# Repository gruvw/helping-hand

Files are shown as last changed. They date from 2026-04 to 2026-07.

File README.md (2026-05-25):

# Helping-Hand



Trigger any button on any remote control using your digital devices.

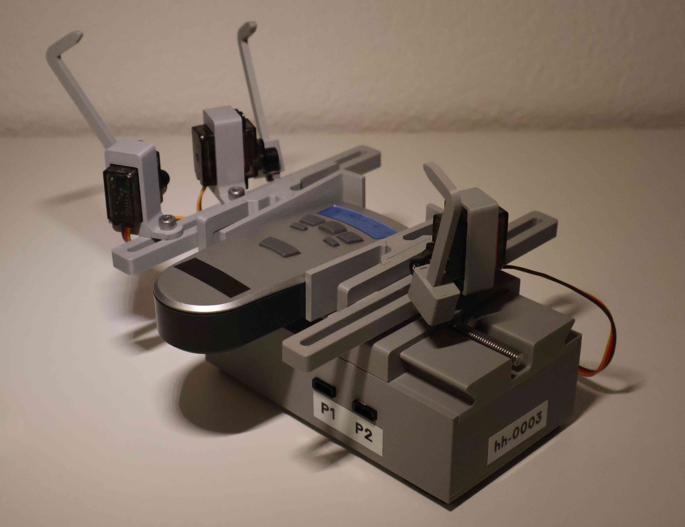
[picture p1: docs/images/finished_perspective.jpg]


This project started from a simple observation: many things already present in our homes are not "smart" or connected, even though they have a remote controller (blinds, garage doors, air conditioning, etc.), and when they are connected, they often each have their own separate mobile application.
On top of that, those applications are often poorly designed, requiring you to create an account to log in, they aren't cross-platform (meaning they are not accessible from a computer, a web browser, or only available on iOS/Android), and are very rarely designed with accessibility in mind.

So instead of replacing a perfectly working home appliance with a commercial "smart" one that comes with the flaws mentioned above, Helping-Hand is an inexpensive solution that adapts to your existing remote controllers.
You can install a remote control inside the device and configure a small servo motor module for each button you want to control.
The device turns your regular remote control into a connected appliance, controllable from a cross-platform application available on your smartphone, tablet, and computer.

You can check out a short video demo of the system, with a focus on its accessibility features: <https://youtu.be/LdWC4-ZtAj0>.

Take a look at the project's [roadmap](docs/roadmap.md) to see upcoming features (along with all the work accomplished).

**Note**: Currently the project's focus is to adapt radio-based remote controls, which are significantly harder to recreate than infrared (IR) based ones for security reasons.
Although the current device can work for IR-based remotes, it probably won't be the most appropriate solution.
The goal is to later create another device that integrates into the same system, dedicated to IR remotes, that will be able to record and replay basic IR command.
Such device won't even require the original remote or servo motors.

## Philosophy

The core principles of the project are the following:

- **Simplicity**: Keep every component as straightforward as possible, complexity is only introduced when strictly necessary. This makes the system easier to understand, maintain, and debug.
- **Modularity**: Allows for using only what you need (nothing more), replacing just the parts that need to be replaced (repairability), and a faster development cycle (iterating only on parts of the system).
- **Open-Source**: Source code, schematics, and designs are fully available and free to inspect, modify, and distribute. This encourages community contributions, trust through transparency, and freedom from vendor lock-in.
- **Accessibility**: Being as inclusive as possible, empowering users with unique needs to control their environment and regain some autonomy.
- **Efficiency**: Keep the system responsive and lean, make actions fast by minimizing latency and loading states where possible.
- **Extensibility**: Designed to be extended; new remotes, arms, rails, components, transports, or platforms can be added without changing what already works.

These principles are fundamental to all parts of the project, whether in system design, hardware, firmware, or software, both in the user-facing parts and on the development side.

## Hardware

The device itself is composed of 3D-printed parts and some easy to find electronic components.
The image below shows the basic parts required to build a Helping-Hand device.

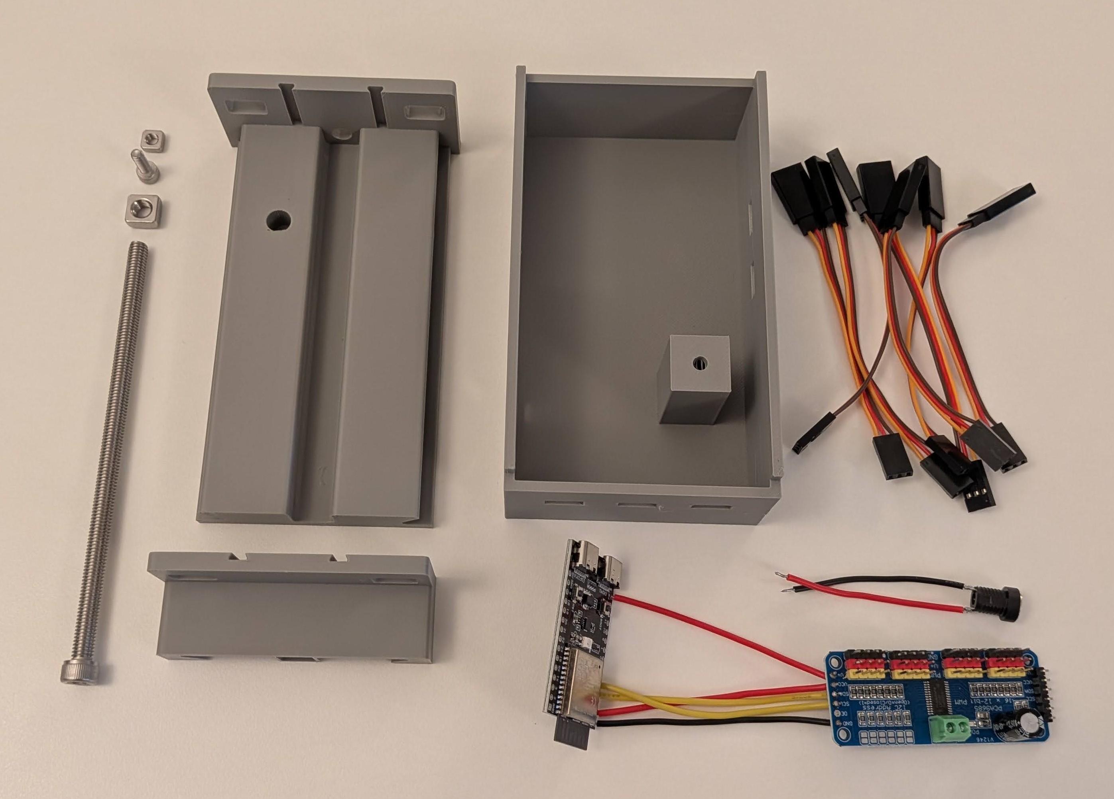
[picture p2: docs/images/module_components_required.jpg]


### 3D Printing

You can find all the CAD models used for this project under the `cad` directory.
It is composed of three main parts.
All parts can be 3D printed without supports, at 15% infill, and using regular PLA filament.

**1. The Device**

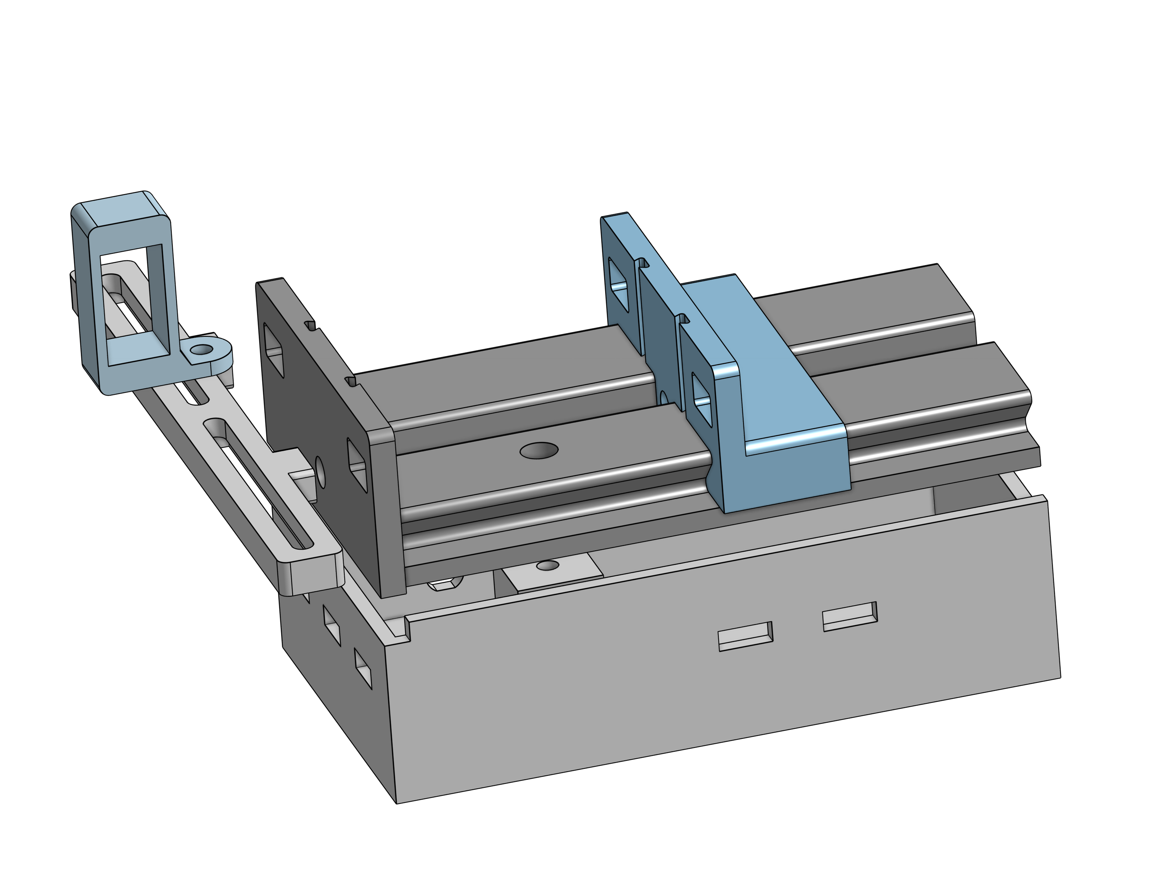
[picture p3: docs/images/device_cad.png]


This is the body of the system.
It has a main box compartment where the electronics sit.
This is closed by placing the main vice rail on top of it, the two pieces are held together by a regular M4 bolt and a square nut.
The vice slides in from the side of the rail.
A 130mm M6 bolt is then passed through into a pressure-fit M6 square nut on the other end.
These are the only two screws on the main body.

The two rails on the sides of the device are pressure-fit into their corresponding holes.
Servo modules can be screwed onto those rails using a short M4 bolt and a square nut under the rail.

**2. The Vice Attachments**

Most remotes will be held in place just fine using the regular inner walls of the vice.

However, some remotes may require special attachments to be properly secured.

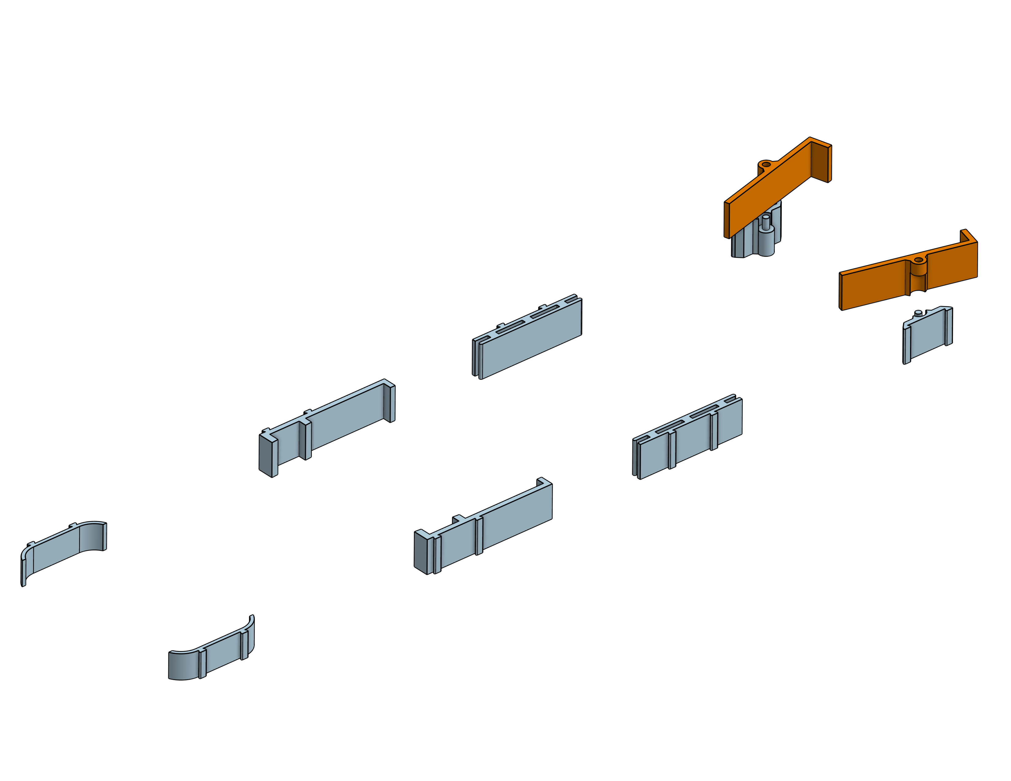
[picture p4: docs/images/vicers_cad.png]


Here are a few ready-to-print attachments that should cover most needs.
There is one for small rounded remotes and another for remotes with angled edges, for example.
These attachments simply slide into the main body using the small inner rails on the vice's walls.

One of these attachments requires the use of a 2mm thick soft silicone sheet to provide a better grip on certain remotes.

**3. The Arms**

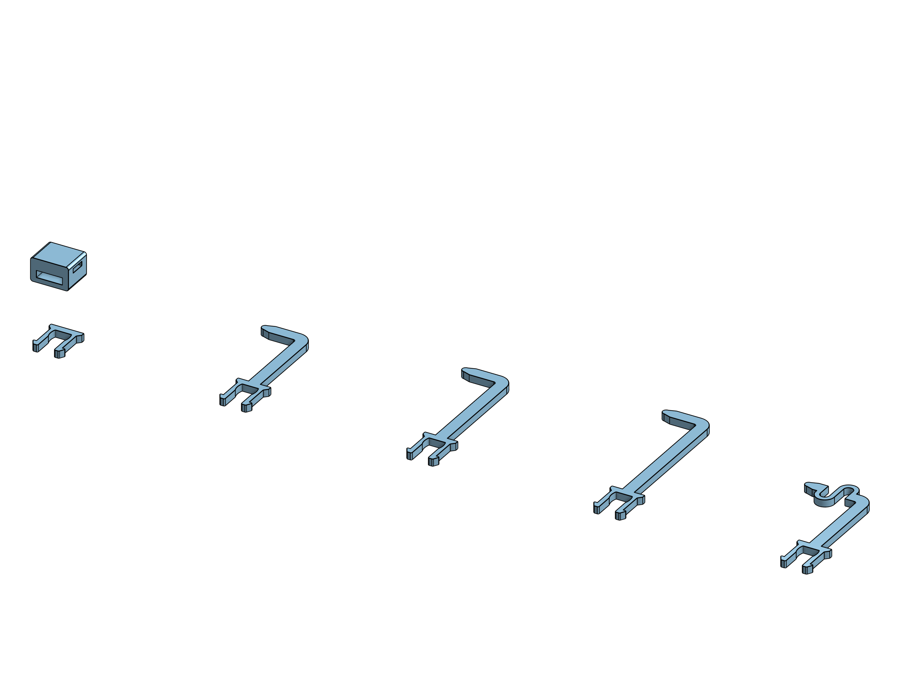
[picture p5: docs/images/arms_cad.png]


Three sizes of arm attachments are already available.
They are designed to clip directly into a buckle glued onto a servo's plastic arm.

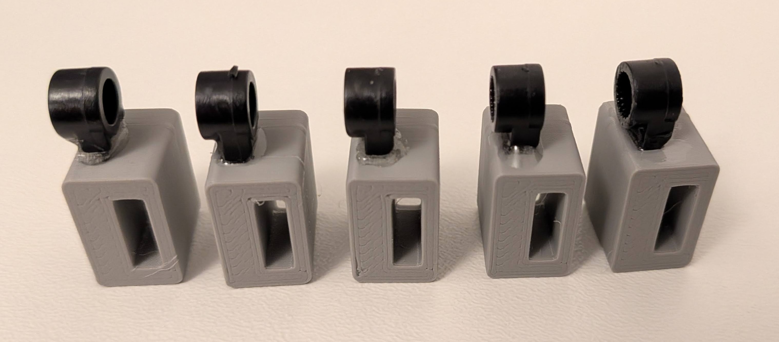
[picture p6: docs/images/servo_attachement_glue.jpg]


The arms are designed to be easily swapped when needed.

To print everything required to build a Helping-Hand module with 4 servo attachments, it takes approximately **5 hours of print time and 200 grams of filament**, depending on your printer and settings.

The entire mechanical design is built with modularity in mind.
There are a total of 4 interface points:

- The servo rail holes on the sides can accommodate different rails if needed.
- The vice attachment system can fit any custom designed walls, as long as they have the slit rails to slide onto the vice's inner walls.
- The servo modules can be swapped to use different kinds of servos, or have a different orientation.
- The servo buckle can be used with all sorts of arms, as long as they share the same base clip.

These interface points serve three main purposes:

- If a part breaks, such as an arm, a rail, or a servo module, you only need to replace that part, not the whole device.
- If a part does not fit your needs, such as for a particularly unusual remote, you can design your own and make it work with the rest of the device.
- You only use the number of parts required for the application: if you only need to access one button, for example, you might use a single rail and a single servo module.

### Electronics

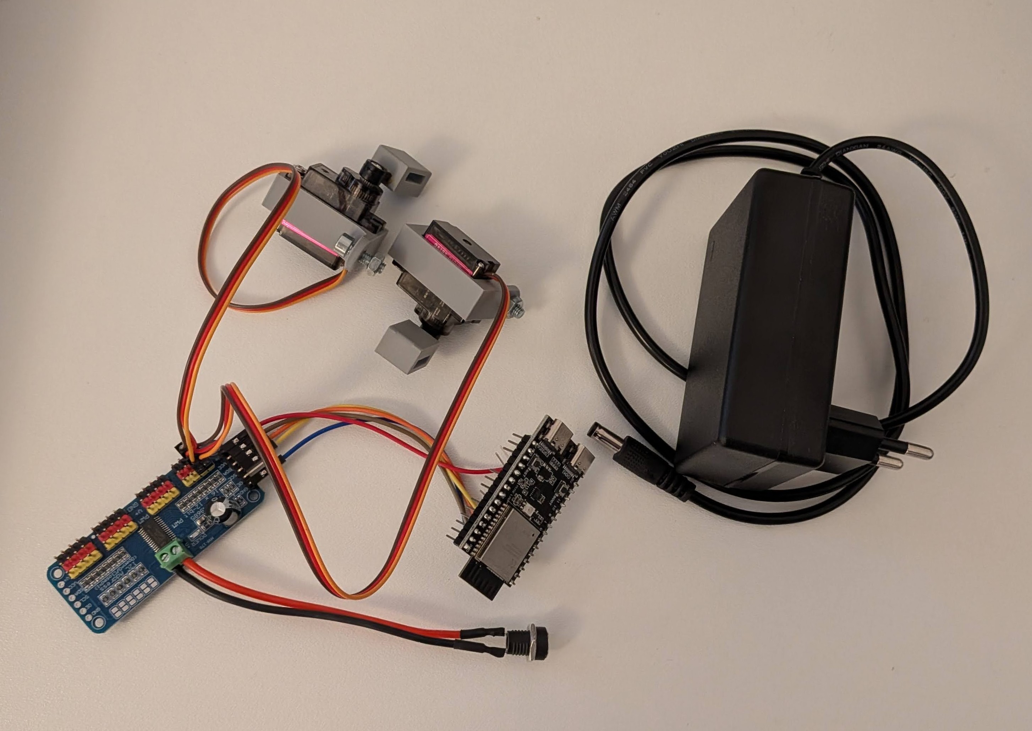
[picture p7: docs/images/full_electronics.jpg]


The electronics required for building a module are the following:

- A 5V 3A power supply
- An ESP-32 C6 microcontroller
- A PCA9685 servo controller
- MG90S servo motors
- A DC plug
- Electronics wires
- (Optionally) JR servo connectors

The image below describes the wiring schematic for the system:

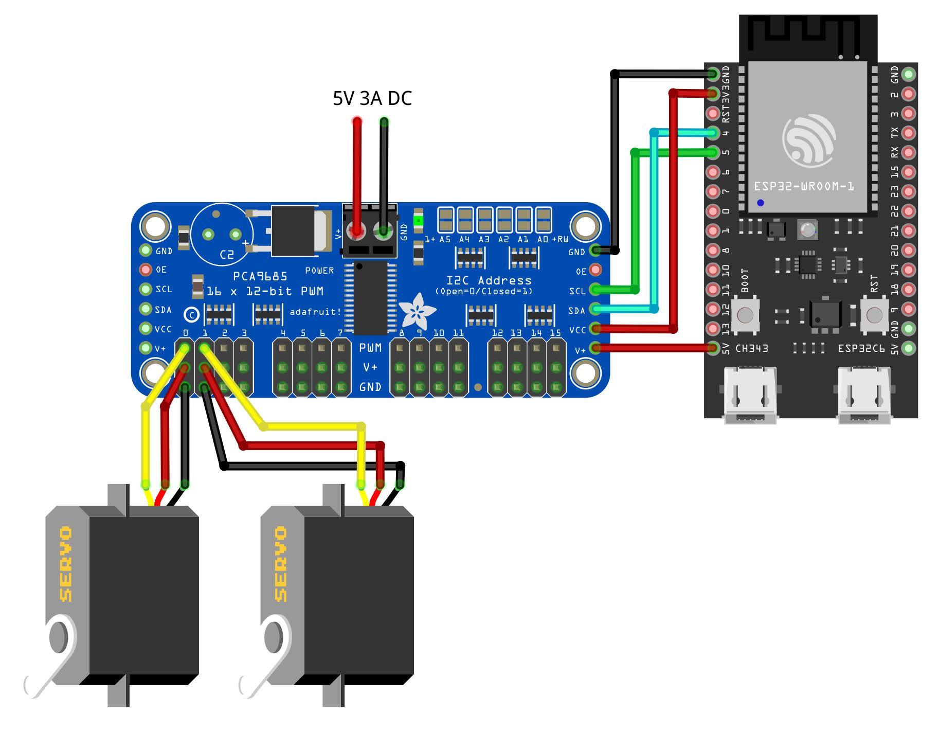
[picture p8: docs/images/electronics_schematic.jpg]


Once everything is connected it should look something like the following:

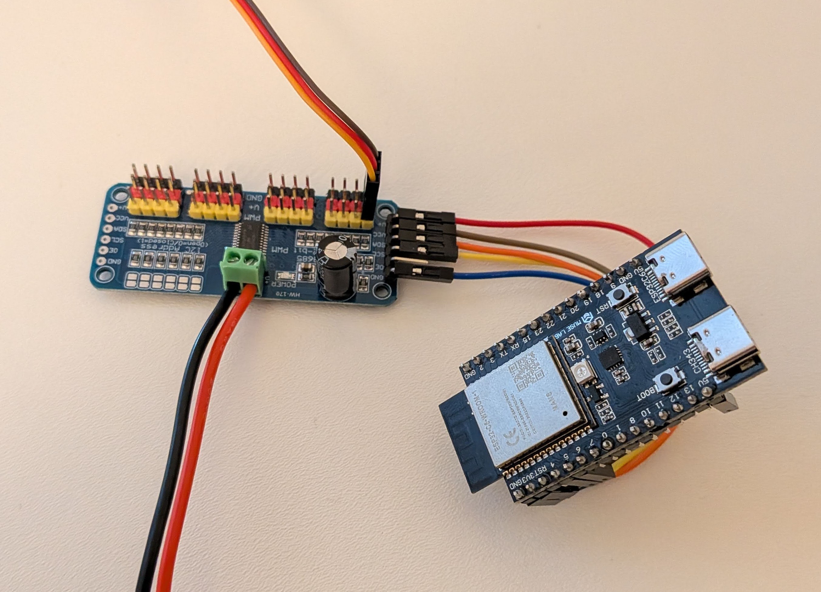
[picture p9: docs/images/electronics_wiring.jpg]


You can then install the electronics inside the main body of the system.
Regular hot glue can be used to fix the components in place, and a stronger glue can be used to secure the cable connectors to holes on the walls.

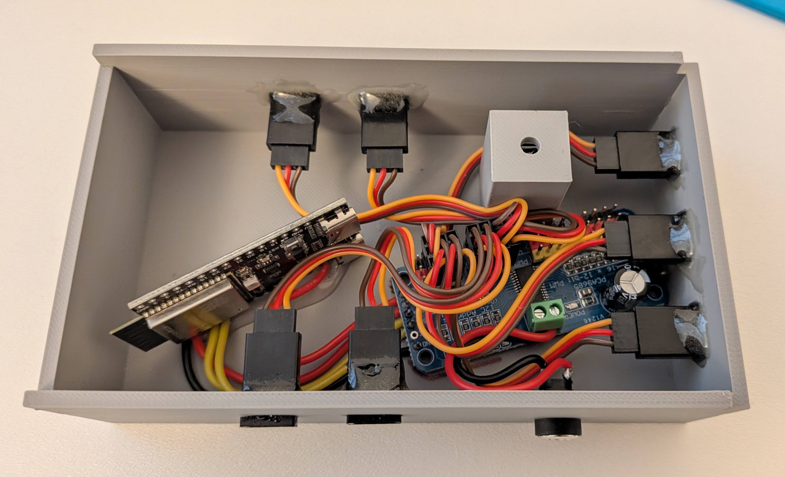
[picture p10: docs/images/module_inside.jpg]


### Finished Device

A fully assembled system looks like the following:

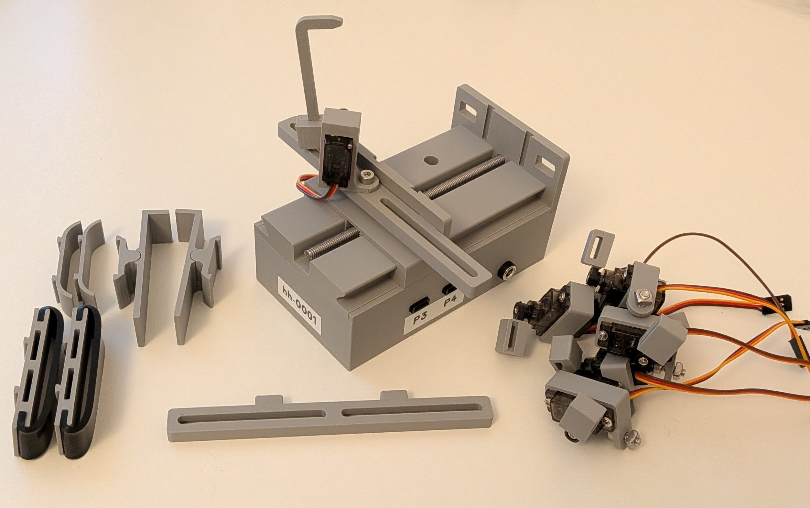
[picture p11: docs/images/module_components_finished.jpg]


Accounting for all necessary materials, the total cost to build a full device is approximately **$46**, and it should take about **2 hours** to fully assemble (not including 3D printing time).

## Firmware

The firmware code for the ESP-32 C6 microcontroller is written in [Rust](https://rust-lang.org/).
The code is under the `firmware` directory.

It uses a modular architecture with 5 main parts:

- The **network** part is responsible for connecting to the Wi-Fi router and runs a reconnection mechanism every 30 seconds in case the connection drops.
- The **server** part is responsible for running an HTTP (and an HTTPS) server to receive and dispatch requests/responses.
- The **logic** part is responsible for handling the requests.
- The **servo** part exposes an API to control the servo motors through the PCA9685 via I2C.
- The **filesystem** part is used to persist the device's configuration across reboots.

The system is configured at build time using a `.env` file containing the following information:

```env
# .env

DEVICE_ID="0001"

NET_SSID="Helping-Hand"
NET_PWD="hh-test-net"
```

### Dev Environment

To compile and flash the firmware, you will need to install the required dependencies.

This process is simplified by using a Nix `flake.nix` file.

Simply run `nix develop` inside the `firmware` directory to have everything ready to go.
Learn more about Nix flakes here: <https://wiki.nixos.org/wiki/Flakes>

Once all dependencies are installed, you can run `cargo build` to build the firmware and `cargo run` to flash an ESP-32 C6 connected via USB.

## Software

The software for the Helping-Hand companion application is built in [Dart](https://dart.dev/) using the [Flutter](https://flutter.dev/) framework.
The code is under the `app` directory.

### User Interface

The companion app for controlling Helping-Hand devices has the following user interface:

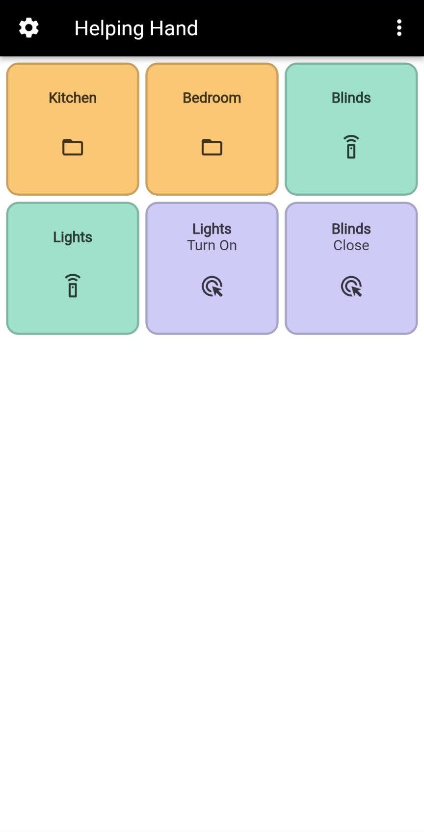
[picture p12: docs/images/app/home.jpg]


When opening the app, the user is taken directly to the home screen shown above.
Here they can find their different remotes and actions organized in tiles.

There are three types of tiles, each with a distinct icon and color:

- **Folder tiles** (orange): Allow grouping other tiles under a named location. The system supports nesting folders as deeply as needed.
- **Remote tiles** (green): Provide access to all the buttons configured on that remote.
- **Action tiles** (purple): Tapping this type of tile triggers a press of the corresponding button on that remote.

Remote tiles contain only the actions configured on the corresponding remote, while folder tiles (and the home screen) can contain any type of tile: folders, remotes, and action tiles directly.
This allows for quick actions directly from the home screen, or for creating a folder containing a subset of buttons from a given remote.

Inside a folder (or on the home page), the user can long-press tiles and then drag and drop to reorder them as desired.

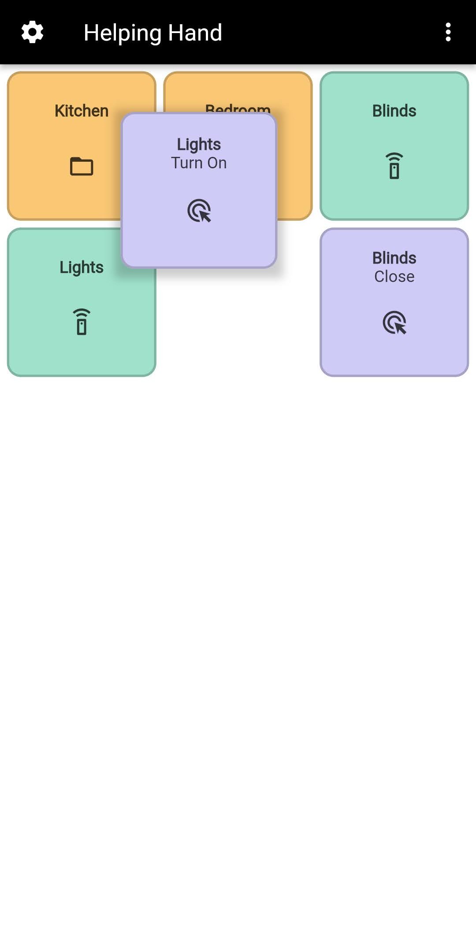
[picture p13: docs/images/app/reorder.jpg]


The user can use the following context menu to change things about the current view:

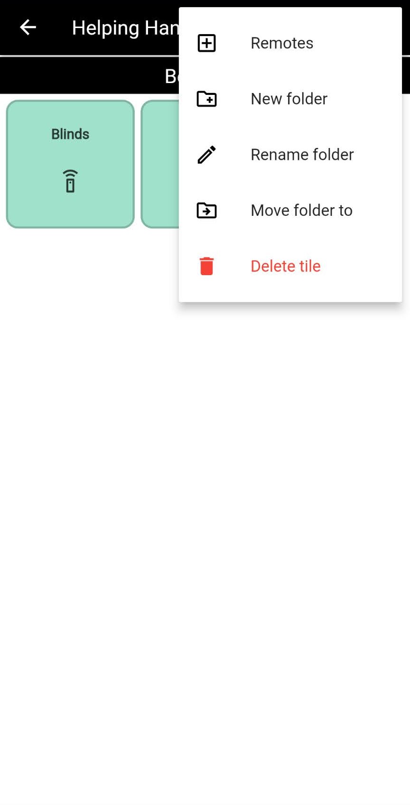
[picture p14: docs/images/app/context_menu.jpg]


This allows for things like creating a new folder, renaming the current one, or moving it to a different location.
The user can also select the "Remotes" option to access the following screen:

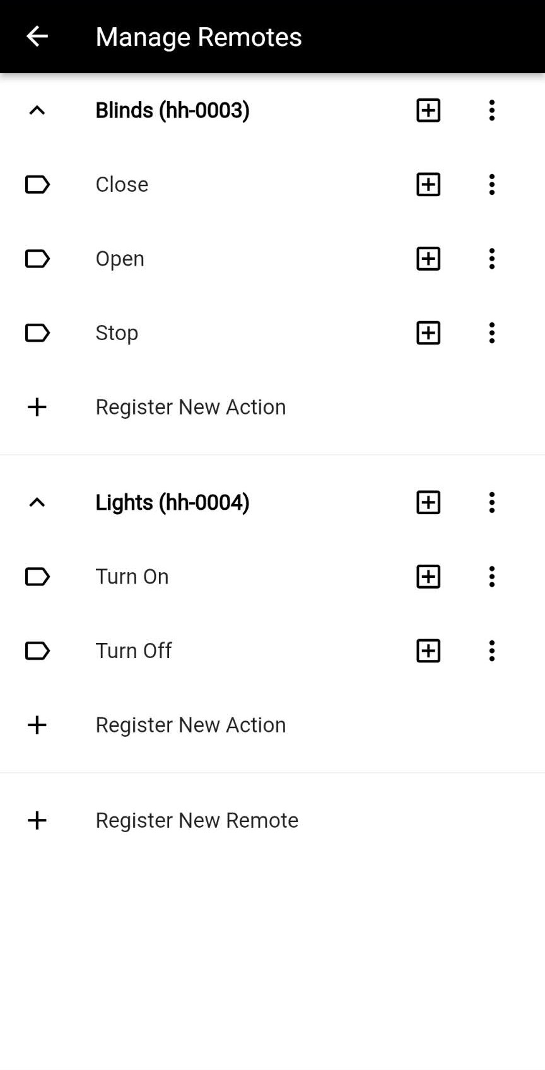
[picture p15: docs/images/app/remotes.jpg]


From here the user can click the "+" icon to add a remote or quick-action tile to the folder they came from.
This is also where the user can add and configure new remotes or buttons.

A remote's configuration is stored directly on the Helping-Hand device itself, not locally on the user's app.
Editing a remote's configuration (renaming it, adding or changing its actions, etc.) is done on this page and will be immediately available to any other user who has that remote installed in their app.
This is intentionally kept separate from the user's tiles referencing those remotes and actions, so that different users can organize their tiles to their liking, on each of their devices.

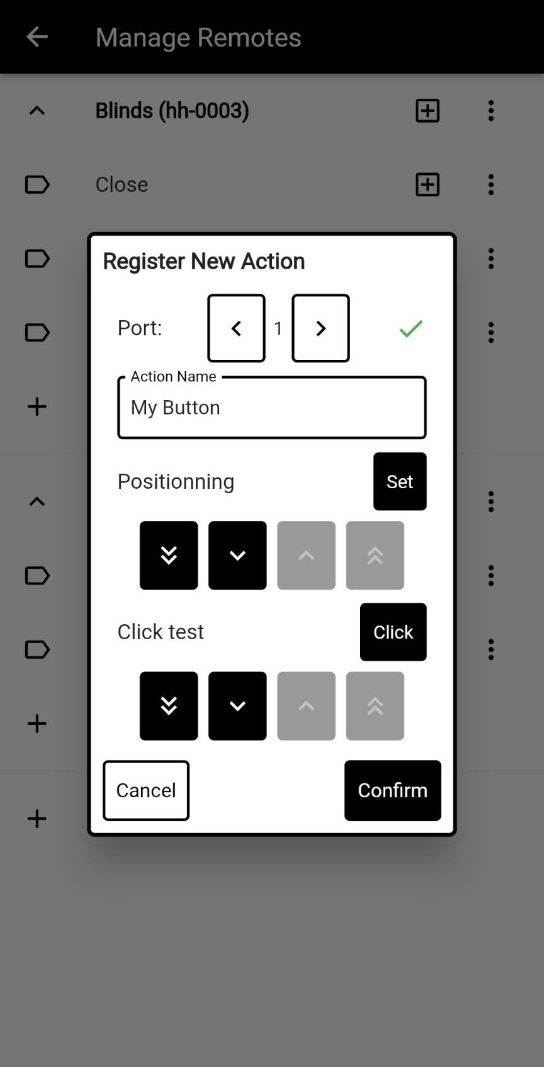
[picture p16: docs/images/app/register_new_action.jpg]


The process for configuring a new button is straightforward and follows the above form's inputs from top to bottom.
First, connect a servo module to one of the available ports on the device.
Then select that port using the arrow keys at the top of the form.
Type in the name of the new button and click on the "Set" button.
This will bring the arm connected to the selected servo module down close to the remote.
You can then use the up and down buttons to bring the servo closer and align it with the button you want to control.
Once it is properly aligned, tighten the screw on the rail and proceed to the "click" test.
Click the lowering button as many times as necessary until the remote registers the click.
Then click "Confirm" to save the new button.

#### Accessibility Mode

This mode is specifically designed for people with disabilities who may use alternative input systems.
For them, precisely targeting a specific tile may be difficult or could cause strain and physical fatigue.
On the home screen, the user (or caregiver) can access the settings and enable accessibility mode by clicking "Use Accessible UI".

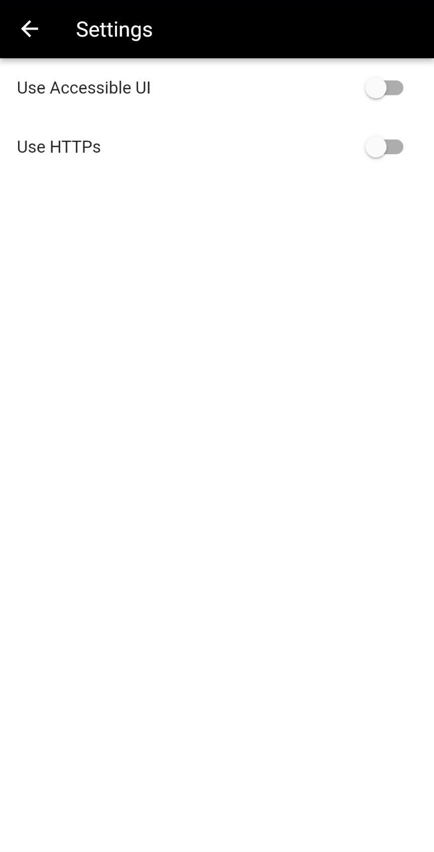
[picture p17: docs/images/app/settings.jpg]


When returning to the home screen after enabling this mode, the system automatically cycles through the tiles, highlighting each one with a blue border in sequence.
Instead of targeting a specific tile, the user can tap anywhere on the screen to select the currently highlighted option.
This significantly increases the active input area and eliminates the need for precise tapping.

In this mode, other main screen actions (such as drag and drop to reorder) are disabled to prevent unintentional actions from harder to control input systems.
The top application bar is still active, as it is used to access the settings to disable accessibility mode.

**Note**: The "Use HTTPS" toggle is explained below (see [Note on iOS Devices](#note-on-ios-devices)).

#### Logo

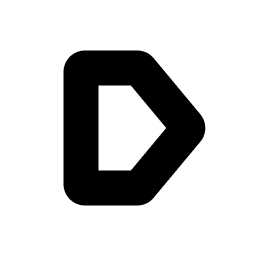
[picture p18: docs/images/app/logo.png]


The image above is the Helping-Hand logo.

It is used as the application icon, the web application's favicon, and is displayed on the splash screen when opening the app.

Its design follows the minimalistic and efficient aesthetic of the app.
The logo carries a dual meaning: it represents a home laid on its side, reflecting the system's home automation purpose, and it resembles a "play" or "do it" button icon, representing the act of performing an action like a button press.

### Dev Environment

Flutter is required to build and deploy the application.
You can follow the installation steps provided on the Flutter website for your system: <https://docs.flutter.dev/install>

Make sure the `flutter doctor -v` command runs without errors after installation.

To run the Helping-Hand application locally, execute the `flutter run` command inside the `app` directory.

Additionally, two build flags are available to facilitate development:

- `--dart-define=DEBUG_FAKE_REQUESTS=true`: Enables a fake interface with two mocked devices, `hh-0001` and `hh-0002`. All requests will have a fake delay and a 30% failure rate to test how the UI handles those cases. (Only has an effect in DEBUG mode.)
- `--dart-define=DEBUG_ERASE_DB=true`: Erases the local database on every build. This is useful for starting from a clean state and ensuring there is no residual state that could cause problems. (Only has an effect in DEBUG mode.)

## Security

As with any digital system, the security model of Helping-Hand is worth discussing.

The main safeguard here is access to your home Wi-Fi network.
Essentially, any device connected to the same Wi-Fi network as a Helping-Hand device is considered trusted to execute actions and reconfigure the device.
Devices outside that network will have no direct access to the device.

This security model therefore relies on having a strong and secure Wi-Fi password.
It also imposes a limitation on the system: it cannot be controlled if you are not connected to your home Wi-Fi.
This means it is not possible to use the system to open and close the blinds while you are away on vacation, for example.

Because the system is built with extensibility in mind, one could use a proxy device, such as a laptop or a Raspberry Pi, connected to the internet, to execute internal requests based on external commands.
Another solution would be to use a home VPN server.
However, either approach would increase the attack surface of the whole system, and therefore their security must be properly ensured.

### Browser Security

Although the Helping-Hand user interface is built with Flutter for cross-platform support, it currently only supports the web target.
This means it must follow the browser security model and account for CSRF protection and mixed-content policies.

The user interface web application must be served over HTTPS, not only for security reasons, but also because it uses the Web Worker API and local storage features, both of which require the site to be served over a secure connection.
This means any requests made by the website must also conform to the HTTPS protocol, as required by the mixed-content policy.
However, ESP32 microcontrollers are not full computers and are on the lower end of the performance spectrum in terms of the memory and CPU required to handle HTTPS connections.

Fortunately, a modern browser feature called [Local Network Access](https://wicg.github.io/local-network-access/) (LNA) allows HTTP requests to local network devices even from an HTTPS served website, thereby bypassing the mixed-content policy.
It simply asks the user to confirm that a given website is authorized to make such requests by showing a confirmation pop-up dialog once.
The firmware is configured to comply with the LNA specification and has the correct preflight request headers set up to inform the browser that this feature is supported.

Additionally, to prevent cross-site request forgery, the ESP-32 must respond to any request with the appropriate allow origin headers.
In debug mode it will allow any port of the `localhost` origin.
In release mode, the firmware only allows requests from a hardcoded URL, defaulting to the official Helping-Hand website's URL.

#### Note on iOS Devices

Apple has strict rules regarding iOS browsers, most notably that they must all use the WebKit engine.
Unfortunately, to this day Apple does not support the LNA browser feature in WebKit, meaning any mixed-content request, even to local network devices that correctly implement the preflight headers, will not be permitted.

This unfortunately necessitates the use of HTTPS to communicate locally with the microcontrollers on iOS devices, at least until Apple decides to implement the LNA feature.
This is currently handled in the project by running an HTTPS server on the microcontroller alongside the regular HTTP server, with a common logic handling process.
The microcontrollers therefore use self-signed certificates for each device, generated at compile time when flashing the chips.

iOS browsers will not accept these self-signed certificates by default, so they must first be downloaded to the iOS device by visiting `http://hh-0001.local/cert` (replacing `hh-0001` with the ID of the target Helping-Hand device).
The user can then follow the procedure described in `./docs/ios_cert.md` to save and trust that certificate.

To finally access the Helping-Hand device from the user interface, the user must enable HTTPS mode from the settings menu.

**Limitations**

This approach currently has 2 major limitations:

- The ESP32 C6 hardware can only support up to 3 simultaneous HTTPS connections.
- Apple's policy on self-signed certificates is that they can only be valid for a maximum of 1 year before automatically expiring. This requires opening the Helping-Hand device to reflash a new certificate once per year.

A more sustainable long-term solution would be to maintain and deploy a native iOS application (which is not cheap), or for Apple to eventually add LNA support to their web engine, or to allow other browser engines on their mobile devices.

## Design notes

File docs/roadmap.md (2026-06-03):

# Roadmap

## Version 0.1.0

- [x] Mechanical design
    - [x] Working vice system with nut and bolt
    - [x] Modular vicer attachments system
    - [x] Provided vicers attachments
        - [x] Without attachments for regular straight remotes
        - [x] Small remotes rounded
        - [x] Tilted remotes, automatic angle
        - [x] Rubber material inserts for trickier remotes
    - [x] Modular rails attachment system (with provided double rails), both sides
    - [x] Modular servo module (with provided default servo module)
    - [x] Modular clippable arms system
    - [x] Provided arms
        - [x] 3 lengths
        - [x] Bendable arm design
    - [x] New longger screws and reprint
- [x] Electronics
    - [x] Alimentation
    - [x] ESP32 C6
    - [x] Servo controller I2C
    - [x] Servo Motors
    - [x] Standalone systems (no PC connection)
- [x] Firmware (Rust)
    - [x] HTTP local webserver
    - [x] Motor control
    - [x] Basic button pressing interface (click)
    - [x] Basic new button setup interface (set + reset)
    - [x] Hardcoded home Wi-Fi credentials
    - [x] Option to run Wi-Fi as AP mode
    - [x] Wi-Fi reconnection system
    - [x] Persisted config store on device + get endpoint
- [x] Software
    - [x] GitHub CI
    - [x] HTTP and web security exploration
    - [x] Basic local DB
    - [x] HTTP security testing and mDNS queries from Android & IOS & desktop
    - [x] New remote registration interface
    - [x] Basic new button setup interface
    - [x] Basic button pressing interface
- [x] Documentation
    - [x] GitHub release
    - [x] Demo video

## Version 1.0.0

- [x] Mechanical design
    - [x] Wider base
    - [x] Electronics enclosure with servo ports
    - [x] Use square nuts designs (at least for rails)
    - [x] Square bottom angle on servo attachment
    - [x] Small user fillets
    - [x] Production of 4 modules
- [x] Electronics
    - [x] Full system soldering
    - [x] Servo one way attachements
- [x] Firmware
    - [x] Refined communication protocol with main application
- [x] Software
    - [x] Remove and rename remote action interface
    - [x] Folder and tiles system
    - [x] Create a remote tile
    - [x] Create a remote action tile
    - [x] Folder creation
    - [x] Rename folder tile
    - [x] Tile deletion
    - [x] Externally removed remote action should remove all tiles with that action
    - [x] Application logo
    - [x] Application splash screen
    - [x] New remote device interface
    - [x] Full set up procedure to configure new buttons/servos
    - [x] Persisted buttons config from app
    - [x] Settings page for configuration
    - [x] Tiles layout and style
    - [x] Tile action feedback display
    - [x] Virtual tile to go back to previous screen on accessible mode
    - [x] Tiles grid with accessible mode design to control multiple devices: auto cycling mode
    - [x] Automatic scroll when moving tiles below screen
    - [x] Automatic scroll when selected goes to tiles off screen in accessible mode
    - [x] Move folder
    - [x] Tiles reordering
    - [x] Phone UI check for sizes, scrolls and overflows
    - [x] Full system test and bug fixing
    - [x] Way to delete quick action tile (double tap)
- [x] Evaluation
    - [x] Stress test the system with 10'000 clicks, one per second
    - [x] Endurance test (50 clicks per day, for a full week)
    - [x] Evaluation of mechanical design for multiple remote types
    - [x] Interface evaluation for ease of manipulation
    - [x] Real world integration testing with measurements
- [x] Documentation
    - [x] Full CAD downloads
    - [x] System pictures
    - [x] Project README
    - [x] GitHub release

## Version 2.0.0

- [ ] Mechanical design
    - [ ] Release downloads with custom tolerances
    - [ ] Try PETG for arms bending
    - [ ] Test Prusa printing
    - [ ] Smaller area under for electronics, might require custom PCB
    - [ ] Two sizes variants (currently one size fits all, too large for very small remotes, one smaller variant with less servos)
    - [ ] New type of arms (bendable, ...)
    - [ ] Arm can hit the rail when retracting back depending on the orientation (have a slightly raised servo holder)
    - [ ] Arm clips are currently a bit britter (try other 3D designs, or other materials like PETG)
- [ ] Electronics + Firmware
    - [ ] Automatic servo port detection
    - [ ] Small OLED status screen or LED
    - [ ] Push button for hardware actions (setup or reset)
    - [ ] Custom PCB
- [ ] Firmware
    - [ ] Connection to Wi-Fi network from AP mode
    - [ ] Captive portal for custom wifi setup
    - [ ] Button double press interface
    - [ ] More complex button actions, like press sequences, even across remotes
- [ ] Software
    - [ ] Device back navigation should pop tiles path
    - [ ] Native application releases (iOS?)
    - [ ] Button long press interface
    - [ ] Button keep pressed interface
    - [ ] User configurable tile rotation time in accessibility mode
    - [ ] Connection to Wi-Fi network from AP mode
    - [ ] Upload custom external lua scripts to the remotes for state control and custom endpoints
    - [ ] i18n
    - [ ] Multiple application profiles if you go to your friend's house for example
    - [ ] Recently used actions tile
    - [ ] Fix tiles reordering animation bug
    - [ ] Import / Export tiles config
    - [ ] Voice control interface
- [ ] Documentation
    - [ ] Web generator application tool for CAD parts (custom tolerances)
    - [ ] Mechanical design modular parts schematics/drawings
- [ ] System
    - [ ] Improve overall set up procedure
        - [ ] Wi-Fi network setup
        - [ ] Servo port detection
        - [ ] Remote action setup
        - [ ] Servo arms (fixed-in screws)
        - [ ] Won't be performed by a user with disabilities, but goal is that even a non technical person could set up the device (like a caregiver)

- [ ] IR replayer compatible module

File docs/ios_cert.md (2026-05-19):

# iOS Certificate Install

Installing a custom certificate on iOS is a three-part process: downloading it, installing the profile, and manually trusting it.

**Step 1**: Download the Certificate

Open Safari and navigate to the link or portal where your certificate is hosted.

Tap the link to download the certificate file.

A pop-up will say, "This website is trying to download a configuration profile." Tap Allow.

A second pop-up will confirm the profile has downloaded. Tap Close.

**Step 2**: Install the Profile

Open your iPhone's Settings app.

Near the top (just under your Apple ID), tap Profile Downloaded.

Tap Install in the top-right corner.

Enter your iPhone passcode when prompted.

You may see a warning screen. Tap Install in the top-right corner, and then tap Install again at the bottom of the screen to confirm.

Tap Done.

**Step 3**: Enable Full Trust (Crucial for Root Certificates)

Note: iOS does not automatically trust manually installed root certificates for SSL/TLS connections. You must enable this manually.
+1

In the Settings app, go to General > About.

Scroll to the very bottom and tap Certificate Trust Settings.

Look under the Enable full trust for root certificates section.

Find the certificate you just installed and toggle the switch to the ON (green) position.

Tap Continue on the prompt confirming you want to trust the certificate.

(If you are installing a certificate issued by a school or employer, they may use Mobile Device Management (MDM) to push the certificate to your phone automatically, in which case you won't need to do this manually.)

# Uninstall iOS Certificate

How to Remove a Profile on iOS

1. Open the Settings app on your iPhone or iPad.
2. Tap on General.
3. Scroll down and tap on VPN & Device Management (on older iOS versions, this may just be called Profiles or Profiles & Device Management).
4. Under the Configuration Profile section, tap the name of the certificate you want to remove.
5. Tap Remove Profile.
6 Enter your device passcode if prompted, and confirm the removal.

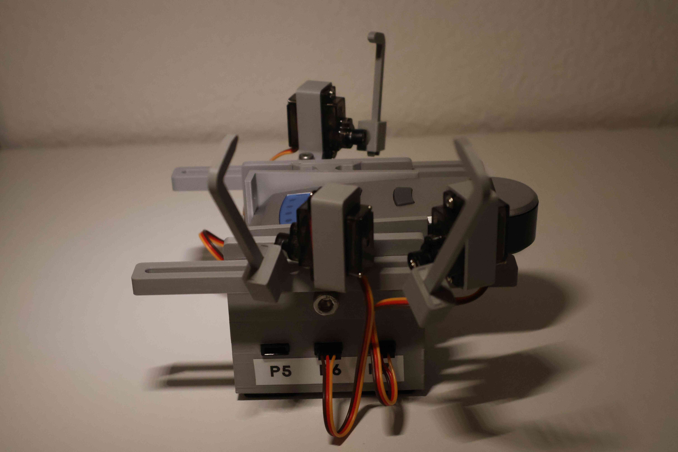
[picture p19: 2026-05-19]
docs/images/finished_side.jpg

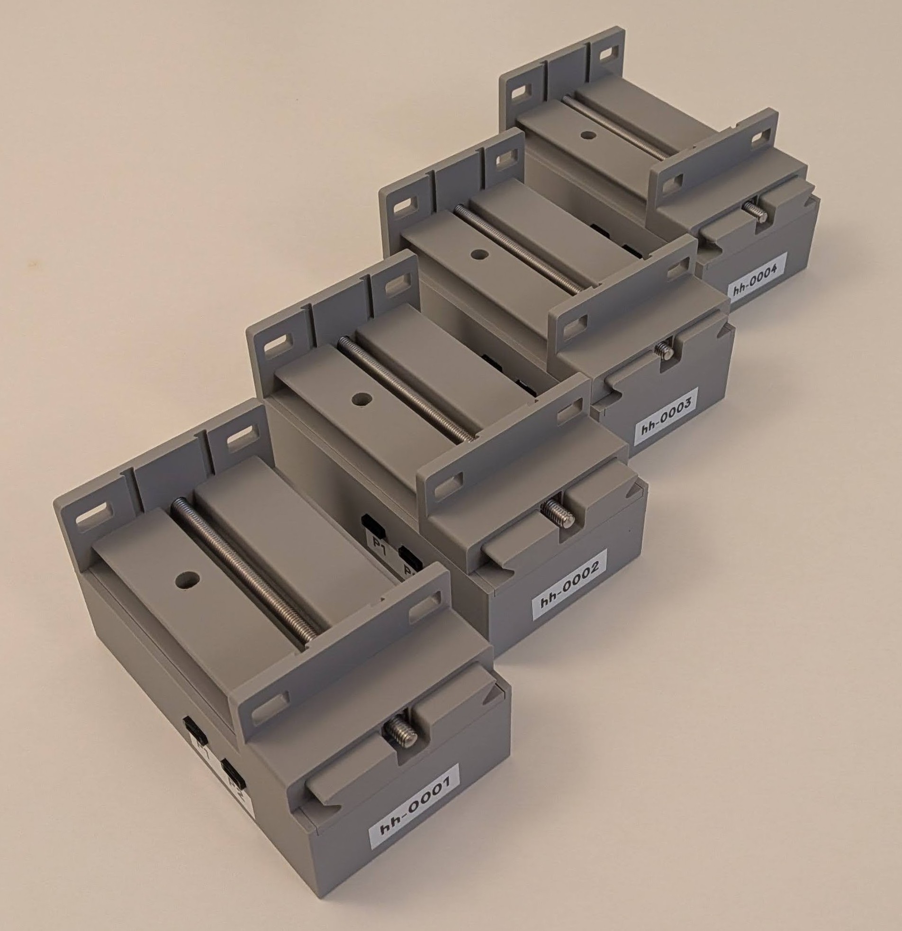
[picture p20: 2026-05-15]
docs/images/four_modules.jpg

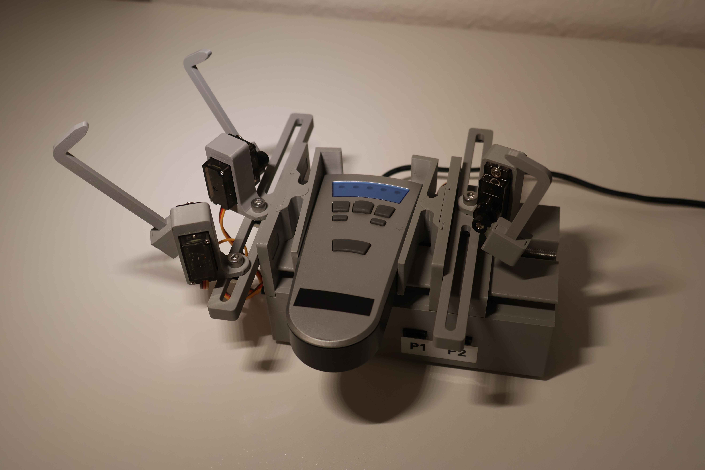
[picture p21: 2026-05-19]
docs/images/finished_top.jpg

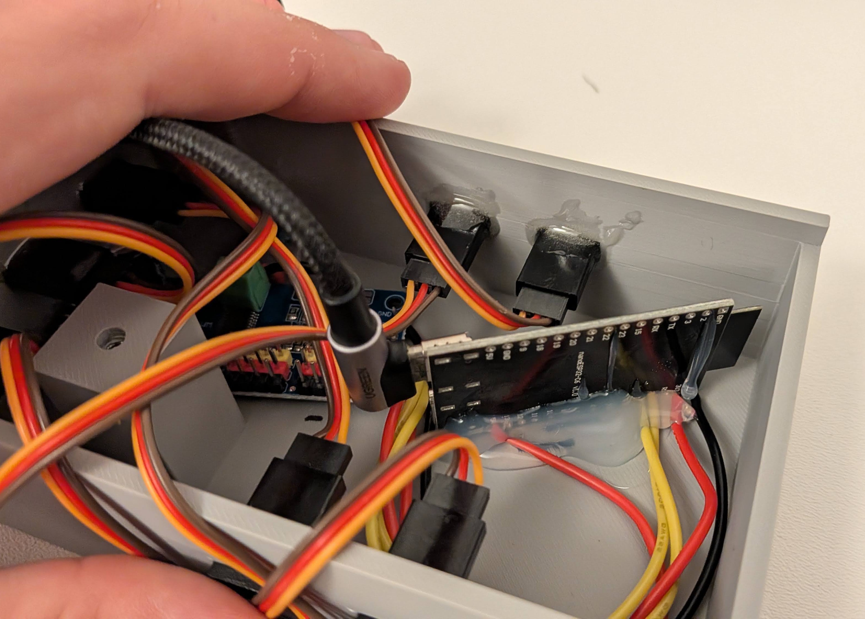
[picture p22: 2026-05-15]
docs/images/module_inside_glue.jpg

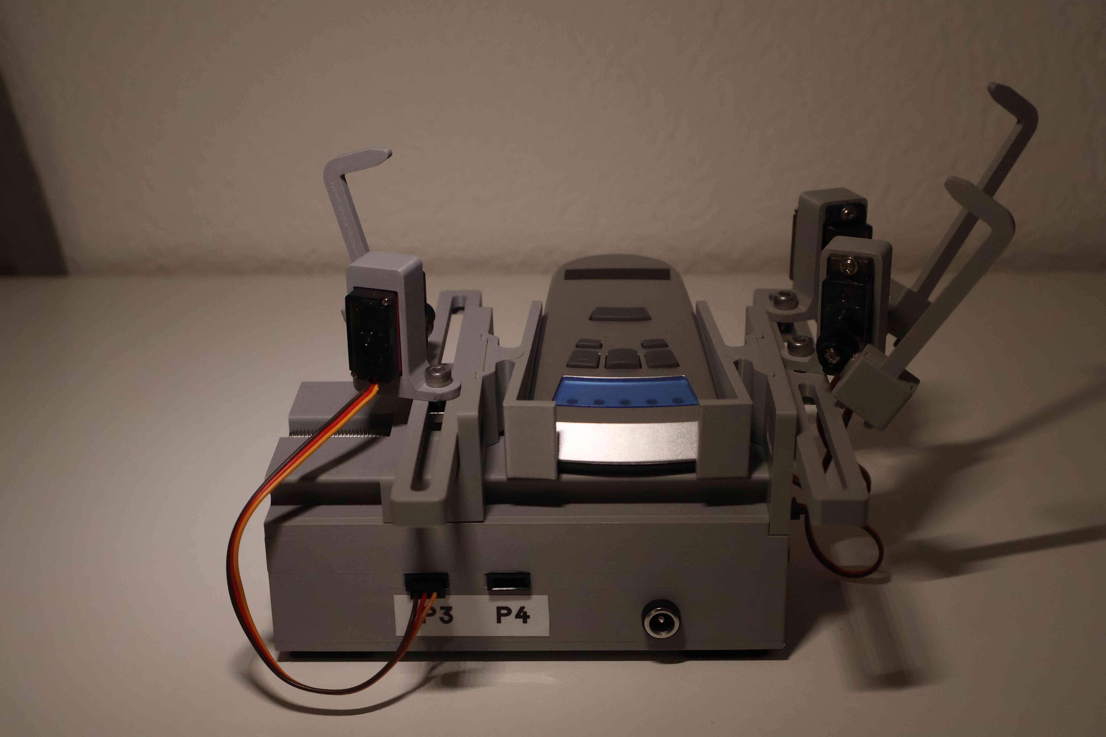
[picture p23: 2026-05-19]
docs/images/finished_back.jpg

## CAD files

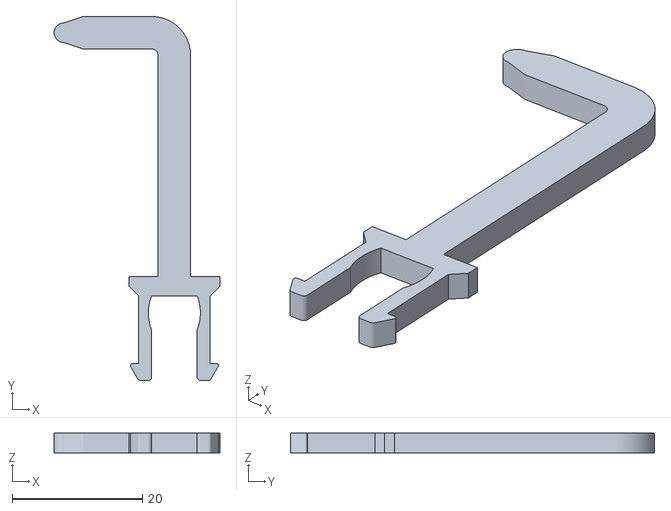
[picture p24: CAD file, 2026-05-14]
cad/arms/arm_basic_small.stl
25.5 x 56.0 x 3.00

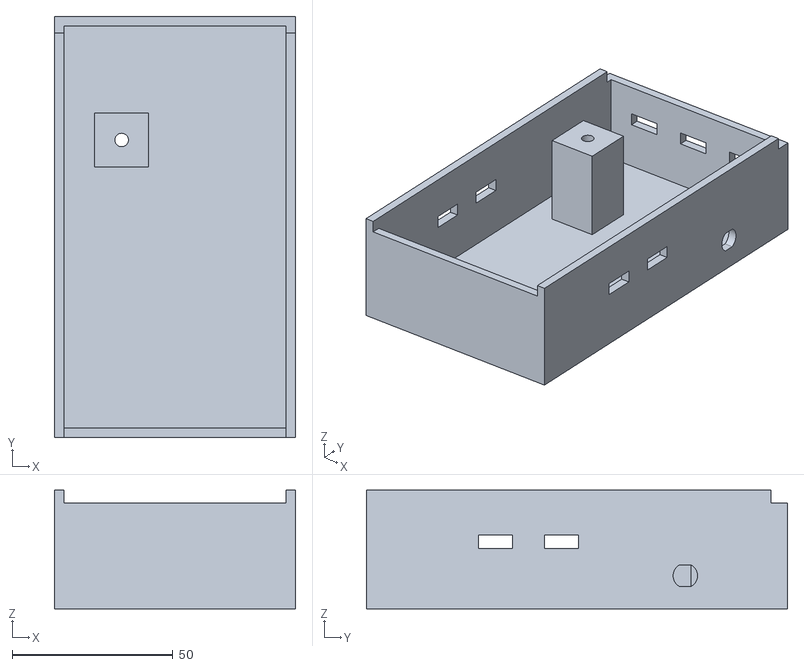
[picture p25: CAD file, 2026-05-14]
cad/device/under.stl
75.0 x 131.0 x 37.0

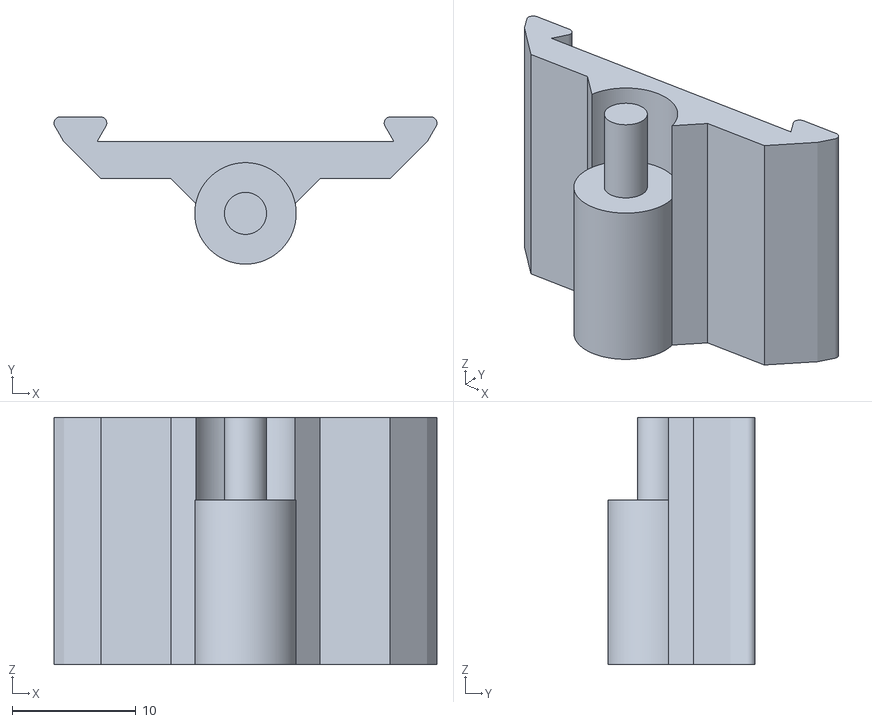
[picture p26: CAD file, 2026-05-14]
cad/vicers/vicer_tilted_bottom.stl
31.0 x 11.9 x 20.0

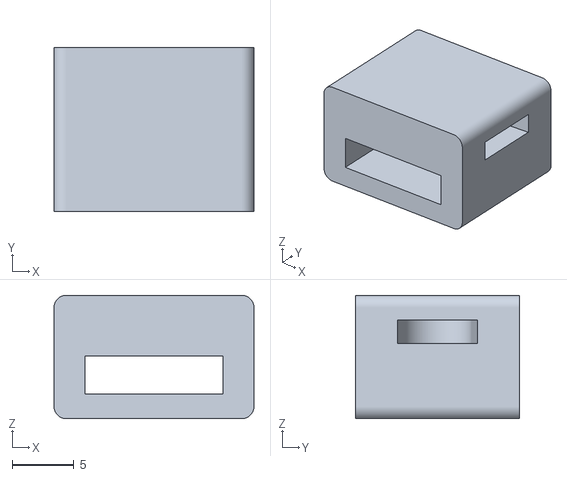
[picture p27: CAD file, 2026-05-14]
cad/arms/buckle.stl
16.2 x 13.3 x 10.0

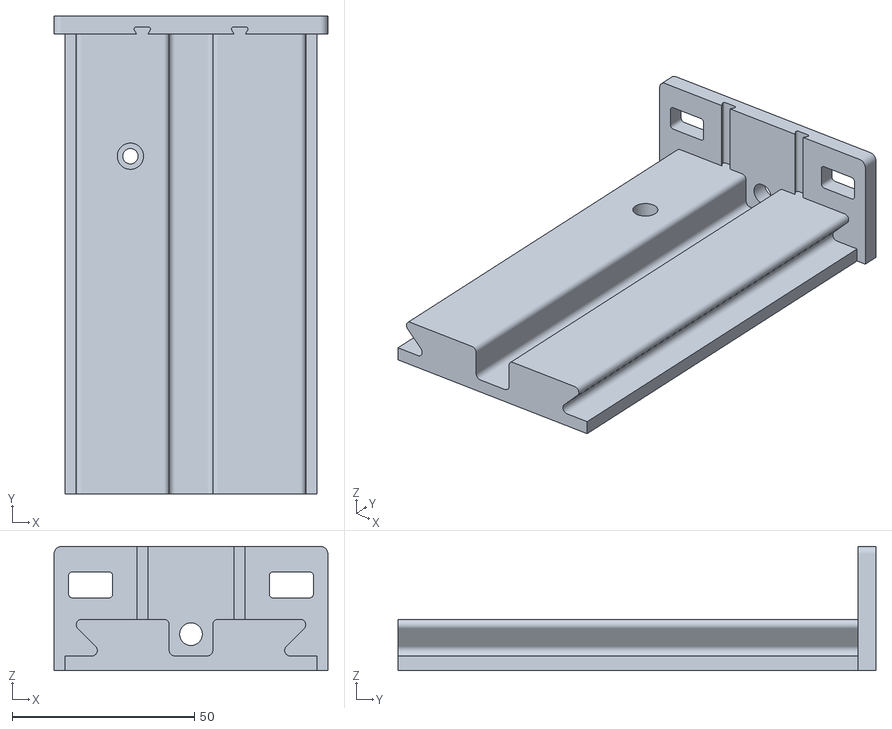
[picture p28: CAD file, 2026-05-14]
cad/device/vice.stl
75.0 x 131.0 x 34.0

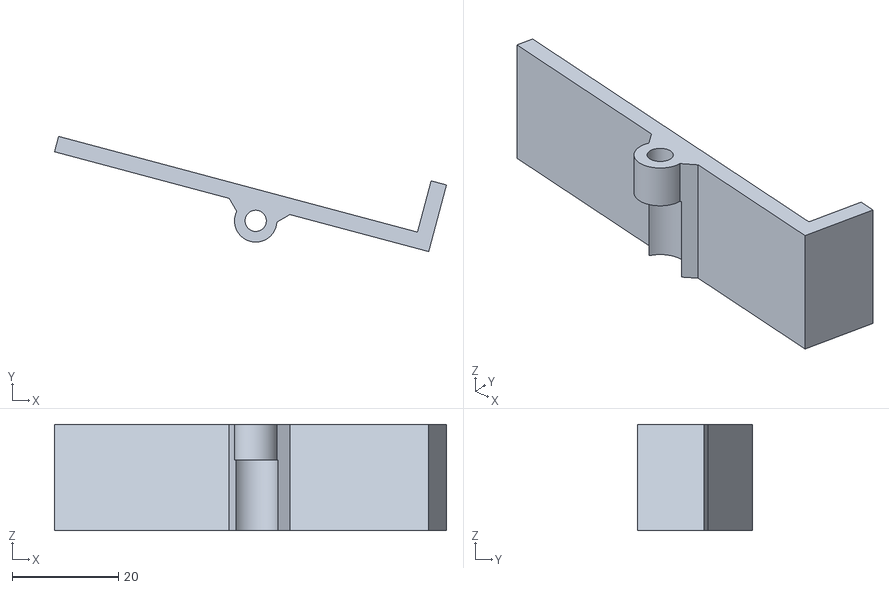
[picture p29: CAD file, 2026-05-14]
cad/vicers/vicer_tilted_top_m.stl
73.9 x 21.7 x 20.0

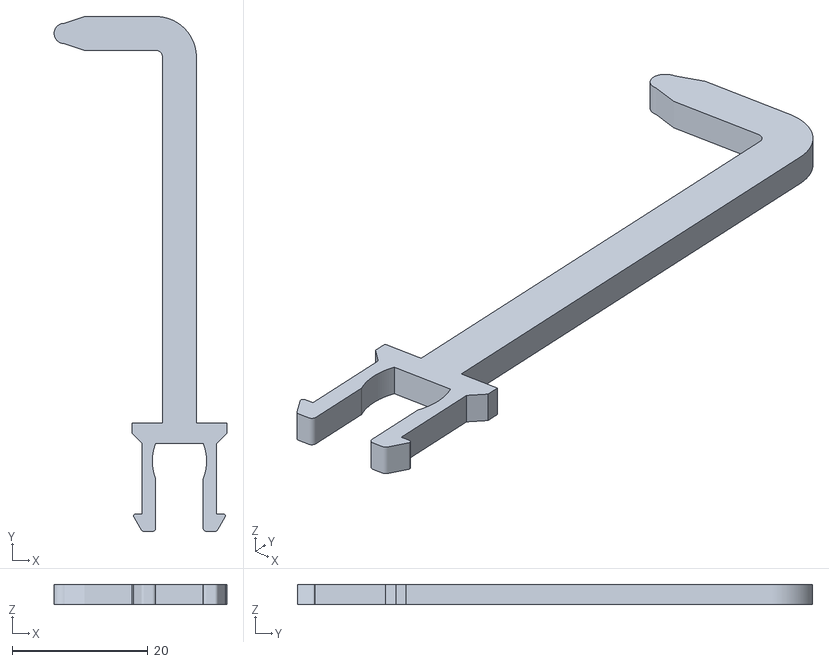
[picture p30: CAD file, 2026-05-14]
cad/arms/arm_basic_large.stl
25.5 x 76.0 x 3.00

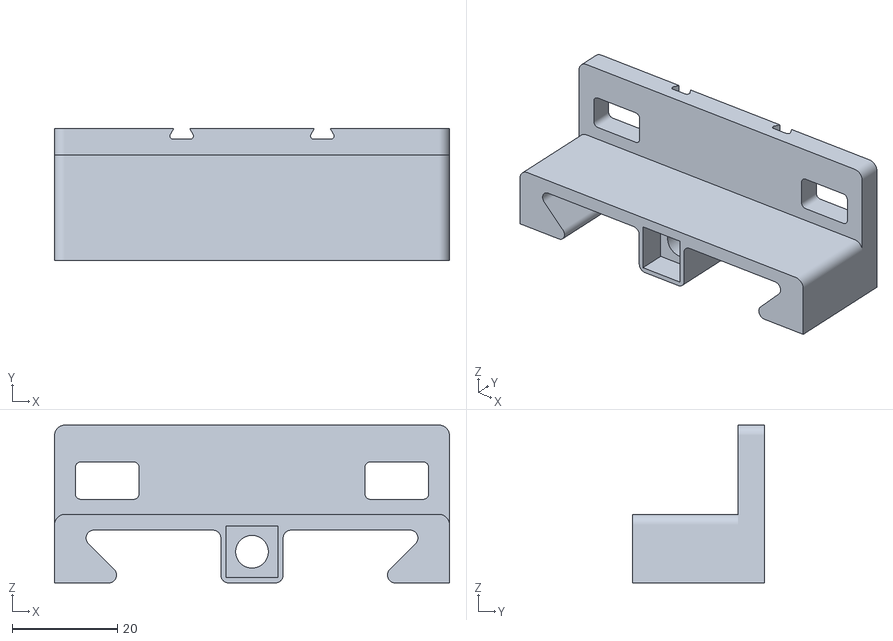
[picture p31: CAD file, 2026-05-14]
cad/device/vice_clamp.stl
75.0 x 25.0 x 30.0

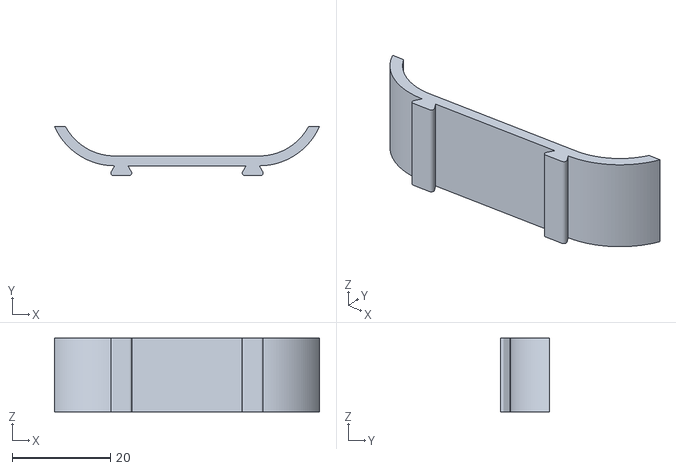
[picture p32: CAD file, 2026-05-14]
cad/vicers/vicer_mini_m.stl
53.8 x 10.0 x 15.0

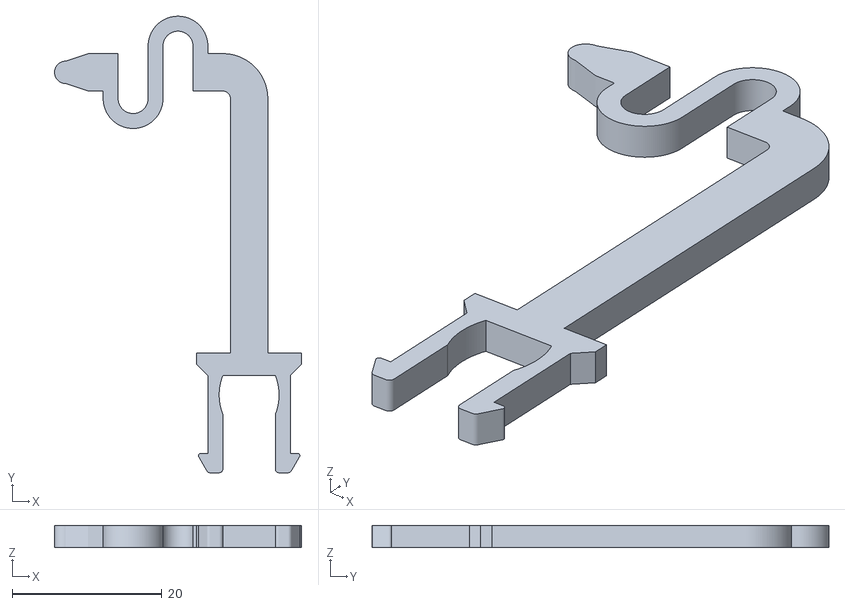
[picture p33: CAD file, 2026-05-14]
cad/arms/arm_bounce.stl
33.0 x 61.0 x 3.00

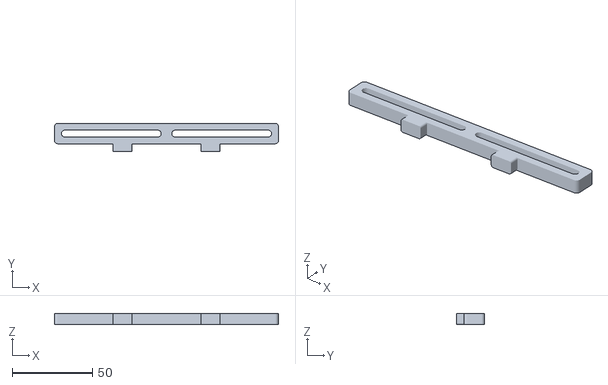
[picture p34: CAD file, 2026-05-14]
cad/device/servo_rail.stl
140.0 x 17.8 x 7.00

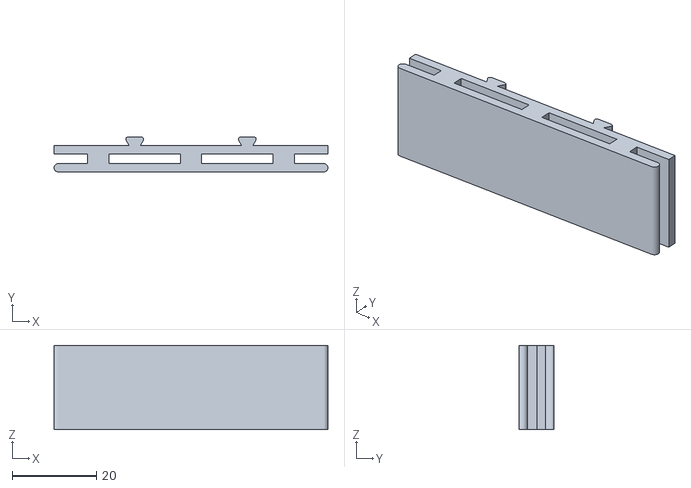
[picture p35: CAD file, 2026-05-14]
cad/vicers/vicer_rubber.stl
65.0 x 8.30 x 20.0

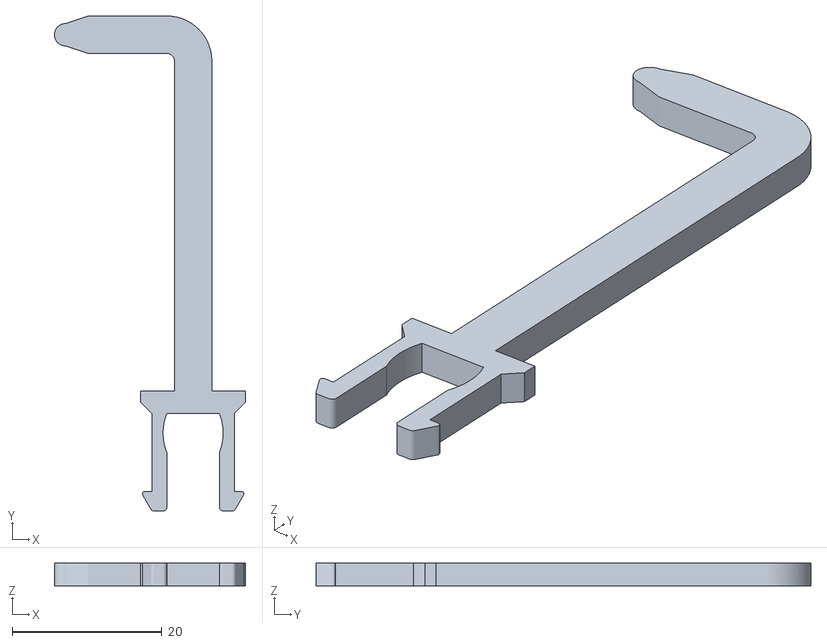
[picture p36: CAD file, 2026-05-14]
cad/arms/arm_basic_medium.stl
25.5 x 66.0 x 3.00

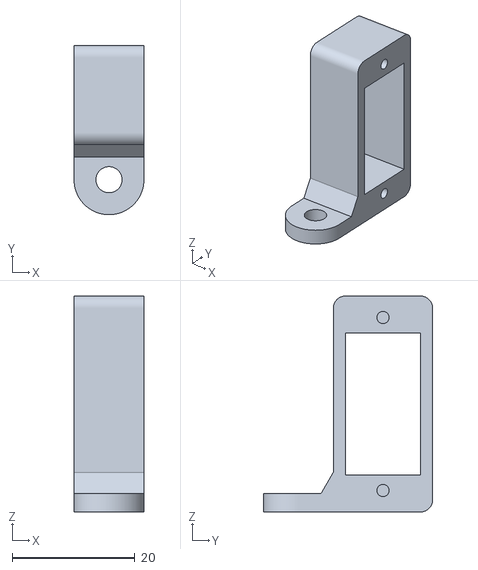
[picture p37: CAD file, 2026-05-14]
cad/device/servo_holder.stl
11.4 x 27.6 x 35.2

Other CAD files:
cad/vicers/vicer_tilted_bottom_m.stl
cad/vicers/vicer_custom_m.stl
cad/vicers/vicer_mini.stl
cad/vicers/vicer_rubber_m.stl
cad/vicers/vicer_custom.stl
cad/vicers/vicer_tilted_top.stl

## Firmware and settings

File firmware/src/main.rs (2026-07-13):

use std::sync::Arc;
use std::sync::Mutex;

use esp_idf_hal::delay::FreeRtos;

use esp_idf_svc::log::EspLogger;
use helping_hand::fs::fs_setup;
use helping_hand::network::network_setup;
use helping_hand::server::server_setup;
use helping_hand::servo::ServoManager;

use esp_idf_hal::peripherals::Peripherals;

use helping_hand::ir::IrManager;

const LOG_TAG: &str = "main";

fn main() -> ! {
    esp_idf_svc::sys::link_patches();
    EspLogger::initialize_default();

    log::info!(target: LOG_TAG, "device started");

    let peripherals = Peripherals::take().expect("failed to take peripherals");

    let _fs = fs_setup();
    let _network = network_setup(peripherals.modem);

    let _server = if env!("DEVICE_ID").starts_with("1") {
        let ir = IrManager::new(peripherals.pins.gpio2, peripherals.pins.gpio3);
        let ir = Arc::new(Mutex::new(ir));

        server_setup(None, Some(ir))
    } else {
        let sm = ServoManager::new(
            peripherals.i2c0,
            peripherals.pins.gpio4, // SDA
            peripherals.pins.gpio5, // SCL
        );
        let sm = Arc::new(Mutex::new(sm));

        server_setup(Some(sm), None)
    };

    log::info!(target: LOG_TAG, "device intitialized");

    // keep alive loop
    loop {
        FreeRtos::delay_ms(u32::MAX);
    }
}

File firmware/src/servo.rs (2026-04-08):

use esp_idf_hal::delay::FreeRtos;
use esp_idf_hal::gpio::{InputPin, OutputPin};
use esp_idf_hal::i2c::{I2c, I2cConfig, I2cDriver};
use pwm_pca9685::{Address, Channel, Pca9685};
use std::time::Duration;

// properties of the servo
const SERVO_FREQUENCY: u32 = 50; // 50 Hz
const SERVO_ANGLE_MIN: f32 = 0.0;
const SERVO_ANGLE_MAX: f32 = 180.0;
const SERVO_ANGLE_MIN_TIME_MS: f32 = 0.5;
const SERVO_ANGLE_MAX_TIME_MS: f32 = 2.5;
const SERVO_ANGLE_SETTLE_MS: u32 = 350;

// properties of the PCA9685
const PCA9685_FREQUENCY: u32 = 25_000_000; // 25 MHz
const PCA9685_RANGE: u32 = 4096; // 12 bits
const I2C_BAUD_RATE: u32 = 100_000; // 100kHz

// derived constants
const SERVO_PERIOD_MS: f32 = 1000.0 / SERVO_FREQUENCY as f32;
const SERVO_ANGLE_MIN_TICKS: u16 =
    (SERVO_ANGLE_MIN_TIME_MS / SERVO_PERIOD_MS * PCA9685_RANGE as f32).round() as u16;
const SERVO_ANGLE_MAX_TICKS: u16 =
    (SERVO_ANGLE_MAX_TIME_MS / SERVO_PERIOD_MS * PCA9685_RANGE as f32).round() as u16;

// prescale formula (PCA9685 datasheet 7.3.5)
// prescale = round(osc_clock / (4096 × update_rate)) − 1
const PCA9685_PRESCALE: u8 =
    (PCA9685_FREQUENCY as f32 / (PCA9685_RANGE * SERVO_FREQUENCY) as f32 - 1.0).round() as u8;

const LOG_TAG: &str = "ServoManager";

pub struct ServoManager<'a> {
    pca: Pca9685<I2cDriver<'a>>,
}

impl<'a> ServoManager<'a> {
    /// Initialises the I2C bus and PCA9685, ready to drive servos.
    pub fn new(
        i2c: impl I2c + 'a,
        sda: impl InputPin + OutputPin + 'a,
        scl: impl InputPin + OutputPin + 'a,
    ) -> Self {
        let config = I2cConfig::new().baudrate(I2C_BAUD_RATE.into());
        let driver =
            I2cDriver::new(i2c, sda, scl, &config).expect("failed to initialise I2C driver");

        let mut pca =
            Pca9685::new(driver, Address::default()).expect("failed to initialise PCA9685");
        pca.set_prescale(PCA9685_PRESCALE)
            .expect("failed to set PCA9685 prescale");
        pca.enable().expect("failed to enable PCA9685");

        log::info!(target: LOG_TAG, "initialized, PCA9685 ready (prescale={})", PCA9685_PRESCALE);

        let mut manager = Self { pca };

        log::info!(target: LOG_TAG, "resetting all channels...");
        manager.reset(Channel::All);

        manager
    }

    /// Set angle for the given `channel`, angle is clamped between `SERVO_ANGLE_MIN` and
    /// `SERVO_ANGLE_MAX`.
    pub fn hold_angle(&mut self, channel: Channel, angle: f32) {
        let angle = angle.clamp(SERVO_ANGLE_MIN, SERVO_ANGLE_MAX);

        // linear interpolation between min and and max angles ticks
        let ticks = (SERVO_ANGLE_MIN_TICKS as f32
            + (angle - SERVO_ANGLE_MIN)
                * ((SERVO_ANGLE_MAX_TICKS - SERVO_ANGLE_MIN_TICKS) as f32
                    / (SERVO_ANGLE_MAX - SERVO_ANGLE_MIN)))
            .round() as u16;

        log::info!(target: LOG_TAG, "hold angle channel {:?} to {}°", channel, angle);

        // signal goes high at time 0, goes low at time `ticks`
        self.pca
            .set_channel_on_off(channel, 0, ticks)
            .expect("failed to set PCA9685 channel on/off");
    }

    fn release(&mut self, channel: Channel) {
        self.pca
            .set_channel_full_off(channel)
            .expect("failed to release channel");

        log::info!(target: LOG_TAG, "release channel {:?}", channel);
    }

    pub fn reset(&mut self, channel: Channel) {
        self.hold_angle(channel, SERVO_ANGLE_MIN);
        FreeRtos::delay_ms(SERVO_ANGLE_SETTLE_MS);
        self.release(channel);
    }

    pub fn click(&mut self, channel: Channel, angle: f32, duration: Duration) {
        self.hold_angle(channel, angle);
        FreeRtos::delay_ms(SERVO_ANGLE_SETTLE_MS);
        FreeRtos::delay_ms(duration.as_millis() as u32);
        self.reset(channel);
    }

    pub fn set(&mut self, channel: Channel, angle: f32) {
        self.hold_angle(channel, angle);
        FreeRtos::delay_ms(SERVO_ANGLE_SETTLE_MS);
    }
}

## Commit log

2026-03-17 feat: working with motor control
2026-03-20 feat: servo sweep working
2026-03-20 feat: servo control and sweep
2026-03-21 feat: refactor servo interface
2026-04-07 feat: network reconnection system
    [partitions.csv]
2026-04-08 feat(firmware): persisted remote config in local FS
    [partitions.csv]
2026-04-12 feat(app): standard buttons and modals
2026-04-16 feat(app): basic functioning remote and buttons interfaces
2026-05-06 feat(app): riverpod `where` helper filter
2026-05-11 feat(app): back button in accessible mode
2026-05-14 feat(cad): add all cad files
    [arm_basic_large.stl, arm_basic_medium.stl, arm_basic_small.stl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]
